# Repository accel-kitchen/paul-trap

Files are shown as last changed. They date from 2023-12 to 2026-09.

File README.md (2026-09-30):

# Printable Paul Trap

This repository contains the 3D-printable parts and assembly documentation for a compact Paul trap designed for physics education. The system consists of a high-voltage power-supply module, a protective enclosure, and a choice of two electrode modules:

- a **ring-electrode module** with integrated illumination and a camera mount; or
- a **linear-electrode module** for quantitative observation and charge-to-mass-ratio measurements.

The repository is intended primarily as a build resource. For the complete photo-based instructions, see the [assembly manual](manual/manual.pdf). Videos of trapped particles are available in the [demonstration playlist](https://www.youtube.com/playlist?list=PLJxrDB4DxPX1ZcciUAjnfQ3G_OaAEvvxG).

> [!CAUTION]
> This apparatus uses **high voltage (up to several kilovolts)**. It is not a toy and must not be assembled or operated without appropriate laboratory supervision. High-voltage and mains-voltage wiring must be performed and inspected by a qualified person. Disconnect the power source, verify that the circuit is de-energized, and discharge the system before touching electrodes, terminals, wiring, or internal components. Follow all applicable electrical-safety rules at your institution.

## Contents

- [Before you start](#before-you-start)
- [Choose a trap configuration](#choose-a-trap-configuration)
- [Recommended build order](#recommended-build-order)
- [3D printing notes](#3d-printing-notes)
- [Parts and materials](#parts-and-materials)
- [Assembly overview](#assembly-overview)
- [Final inspection and commissioning](#final-inspection-and-commissioning)
- [Repository layout](#repository-layout)
- [Publication](#publication)
- [License](#license)

## Before you start

1. Read this README and the complete [assembly manual](manual/manual.pdf).
2. Choose either the ring-electrode or linear-electrode configuration.
3. Print all required STL files before purchasing or modifying hardware.
4. Dry-fit the printed parts and check all screw holes, slots, camera mounts, and cable routes.
5. Assemble and test the mechanical and low-voltage sections first.
6. Do not connect the high-voltage source until the entire assembly has been inspected.

The STL files are provided as finished meshes. Source CAD files and printer-specific slicing profiles are not included, so print tolerances may need to be adjusted for your printer.

## Choose a trap configuration

| Configuration | Main features | Important notes |
| --- | --- | --- |
| **Ring electrode** | Ring electrode with two endcaps, integrated LED illumination, internal camera mount, compact enclosure | The more integrated of the two designs. The documented electrode spacing was designed for operation up to 6 kV. |
| **Linear electrode** | Four-rod quadrupole, optional ruler for image calibration, separate bottom plate | This design is an experimental prototype and is less integrated. The documented setup used an external camera, an acrylic enclosure, and a laser pointer. The applied voltage was limited to approximately 2.1 kV. |

The quoted voltages describe the documented apparatus; they are **not** general operating recommendations. Safe limits depend on construction quality, insulation, electrode spacing, environment, and institutional procedures.

## Recommended build order

Build the modules in the following order:

1. **Shielding box** — protects trapped particles from air currents and reduces stray light.
2. **Power-supply enclosure** — houses the high-voltage transformer and switch.
3. **Electrode module** — assemble either the ring-electrode or linear-electrode version.
4. **Illumination and imaging** — install the LED or external light source and align the camera.
5. **Mechanical inspection** — check fasteners, clearances, cable strain relief, and exposed conductors.
6. **Electrical inspection and commissioning** — to be performed under qualified supervision.

## 3D printing notes

- Print the STL files at their original scale unless you intentionally redesign the mating parts.
- Use an opaque black material for `shielding_box.stl`, or paint the inside black, to reduce stray light.
- The M3 holes in the shielding box are modeled at approximately 3 mm and are not pre-tapped.
- Several press-fit parts are intentionally tight. Remove supports and clean edges before applying force.
- Check that conductive parts, screws, and wires cannot cut into insulation or contact the enclosure unexpectedly.
- Inspect printed parts for cracks, delamination, heat damage, and sharp edges before use.

## Parts and materials

The following lists summarize the hardware used in the documented build. Equivalent components may be used only after checking their electrical, mechanical, and safety ratings.

### Shielding box

Printed parts:

- [`shielding_box.stl`](stl_file/shielding_box/shielding_box.stl)
- [`window.stl`](stl_file/shielding_box/window.stl)

Additional hardware:

- M3 screws

### Power-supply module

Printed parts:

- [`power_supply_module_box.stl`](stl_file/power_supply_module/power_supply_module_box.stl)
- [`power_supply_module_box_lid.stl`](stl_file/power_supply_module/power_supply_module_box_lid.stl)

Components used in the documented build:

- toggle switch: S-21A, NKK Switches
- high-voltage transformer: UFO-6K-001-P100, Union Electric
- appropriately rated power cable
- two banana plugs
- suitable screws and nuts for securing the transformer

The documented transformer accepts 50/60 Hz AC at 0–100 V and has a nominal voltage ratio of 60. Treat both the input wiring and output wiring as hazardous.

### Ring-electrode module

Printed electrode parts:

- [`ring_electrode.stl`](stl_file/ring_type/ring_electrode.stl)
- [`endcap.stl`](stl_file/ring_type/endcap.stl)
- [`electrode_holder.stl`](stl_file/ring_type/electrode_holder.stl)

Printed enclosure and accessory parts:

- [`ring_trap_box.stl`](stl_file/ring_type/ring_trap_box.stl)
- [`ring_trap_box_lid.stl`](stl_file/ring_type/ring_trap_box_lid.stl)
- [`LED_holder.stl`](stl_file/ring_type/LED_holder.stl)
- [`camera_jig.stl`](stl_file/ring_type/camera_jig.stl)

Electrode hardware:

- conductive paint (SKU-0216, Bare Conductive, in the documented build)
- M3 low-profile screws, 4 mm
- jumper wires and crimp terminals
- M4 screws, 10 mm; hex-socket screws are recommended

Illumination and imaging:

- bright LED, preferably blue-toned
- breadboard, jumper wires, resistor, and 9 V battery
- toggle switch: RS PRO 448-0753
- battery strap: RS PRO 489-021
- USB camera: USB130W01MT-MF40-J in the documented build
- 1/4-inch camera screw

Main-body hardware:

- two banana sockets: Stäubli 23.3020-21
- two 10 MΩ resistors: TE Connectivity HB110MFZRE
- crimp terminals and insulated wiring

### Linear-electrode module

Printed parts:

- [`electrode_jig1.stl`](stl_file/linear_type/electrode_jig1.stl)
- [`electrode_jig2.stl`](stl_file/linear_type/electrode_jig2.stl)
- two copies of [`electrode_jig_stopper.stl`](stl_file/linear_type/electrode_jig_stopper.stl)
- [`linear_trap_box.stl`](stl_file/linear_type/linear_trap_box.stl)
- [`linear_trap_box_lid.stl`](stl_file/linear_type/linear_trap_box_lid.stl)
- [`ruler_jig.stl`](stl_file/linear_type/ruler_jig.stl)

Additional hardware:

- four metal rods, approximately 3 mm in diameter and 75 mm long
- insulated wire and crimp terminals
- conductive metal plate, approximately 55 × 55 × 3 mm
- three banana sockets: Stäubli 23.3020-21
- two 10 MΩ resistors: TE Connectivity HB110MFZRE
- ruler for image calibration, if required
- external camera and enclosure; the documented setup used a Logicool C920n camera and an acrylic box

## Assembly overview

This section provides the build sequence. Refer to the [assembly manual](manual/manual.pdf) and the photographs under [`img/`](img/) for detailed views.

### 1. Shielding box

1. Print the box and window.
2. Clean the mating surfaces and verify that the window opens and closes freely.
3. Attach the window using M3 hardware.
4. If the enclosure is not opaque, paint the inside black before installing the trap.

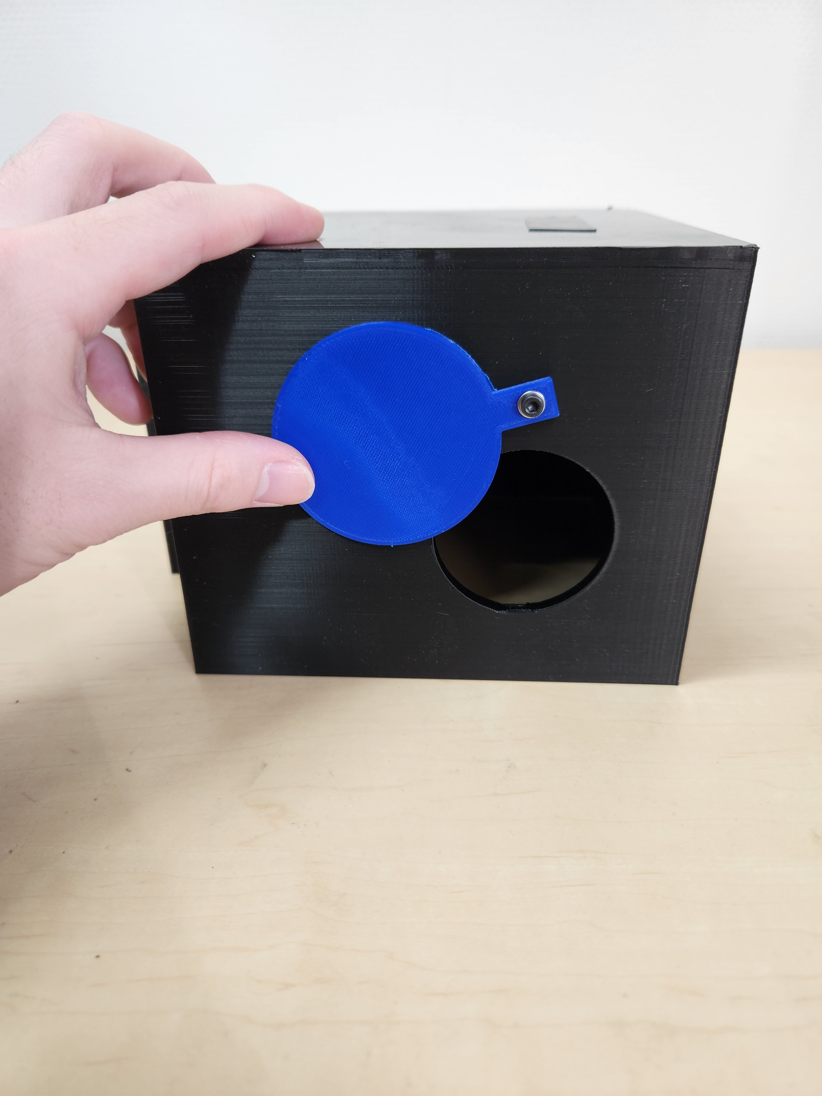
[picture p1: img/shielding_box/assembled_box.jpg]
Assembled shielding box


### 2. Power-supply enclosure

> [!WARNING]
> Do not perform mains-voltage or high-voltage wiring unless you are qualified to do so. The enclosure does not make an incorrectly wired circuit safe.

1. Print the enclosure and lid, then dry-fit the transformer, switch, cables, and banana connectors.
2. Have a qualified person complete and inspect the electrical wiring shown in the manual.
3. Secure the transformer so that it cannot move or strain the wiring.
4. Add strain relief and insulation appropriate for the cable and voltage ratings.
5. Close the enclosure before any energized test.

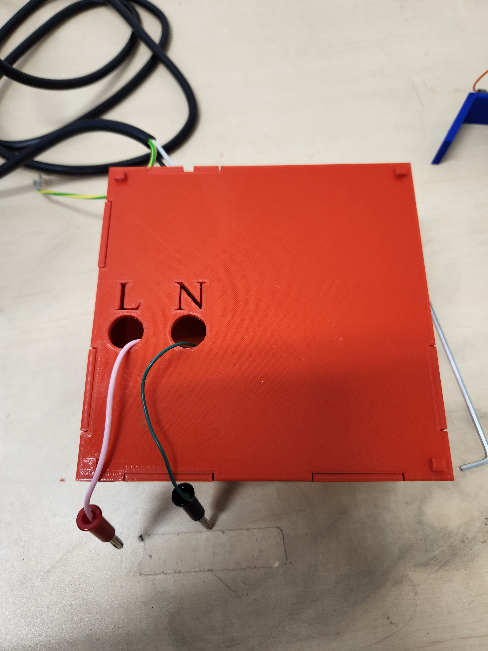
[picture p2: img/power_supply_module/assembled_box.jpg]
Assembled power-supply enclosure


### 3A. Ring-electrode module

1. Apply conductive paint to the ring electrode and both endcaps. Allow it to dry completely; apply additional coats if coverage is poor.
2. Prepare wires with crimp terminals and attach them to the electrodes using the low-profile screws.
3. Mount the electrodes in `electrode_holder.stl`, keeping the orientation shown in the manual.
4. Assemble and test the LED circuit separately at low voltage.
5. Install the two banana sockets in the main enclosure.
6. Install one 10 MΩ series resistor between each high-voltage input and its electrode connection, following the documented wiring and institutional safety requirements.
7. Place the LED circuit inside the enclosure and route the LED and electrode leads through the lid.
8. Install the camera jig and camera.
9. Insert the electrode holder and LED holder into the lid, then connect the electrode leads to the resistor terminals.
10. Confirm that the ring and endcaps are aligned and that no exposed conductor can contact the enclosure or camera hardware.

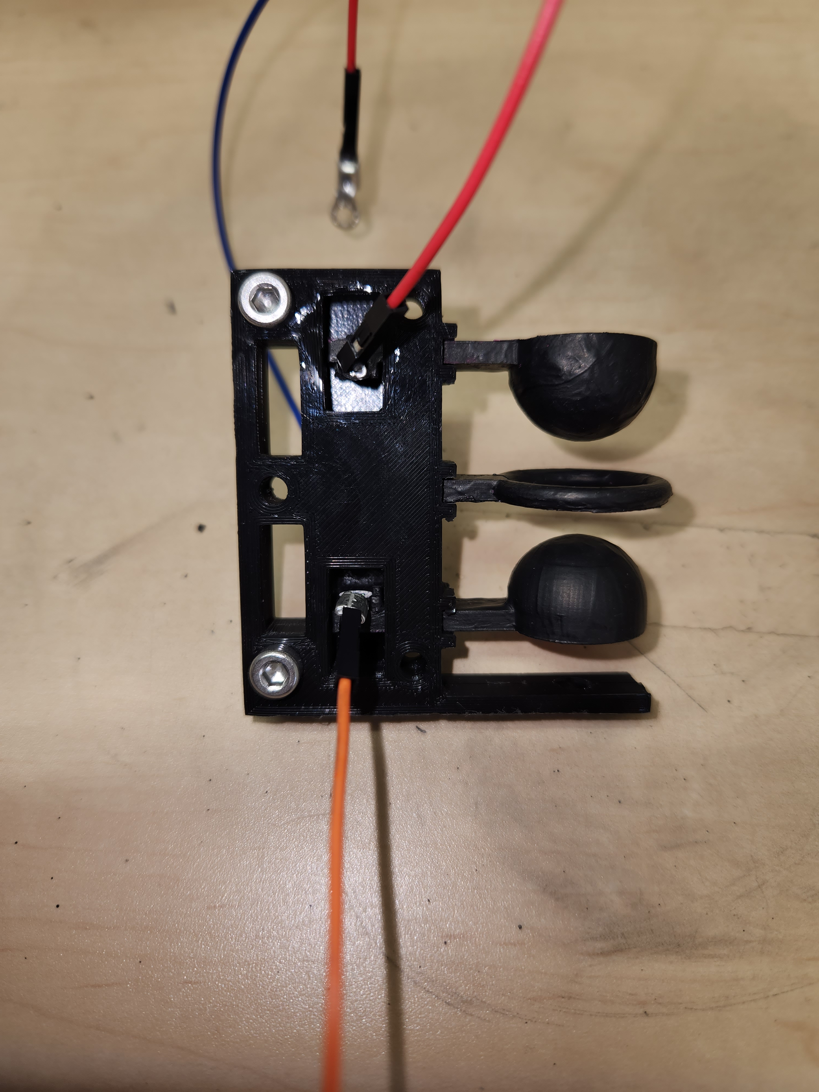
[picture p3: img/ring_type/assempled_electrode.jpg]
Ring-electrode assembly


### 3B. Linear-electrode module

1. Insert the four metal rods into `electrode_jig1.stl`.
2. Fit `electrode_jig2.stl` over the rods and secure the assembly.
3. Wire diagonally opposite rods together to form the two electrode pairs of the quadrupole.
4. Route the wires away from adjacent conductors and add insulation where discharge could occur.
5. Lock the electrode assembly into the enclosure using the two printed stoppers.
6. Prepare the bottom plate and provide a secure electrical connection to it.
7. Install the three banana sockets: two for the quadrupole supply and one for the bottom plate.
8. Install the two 10 MΩ series resistors on the high-voltage inputs.
9. Place the bottom plate in the lid, connect it, close the enclosure, and install the electrode assembly.
10. If required, install the ruler and ruler jig for image calibration.
11. Place the complete trap inside a suitable protective enclosure and align the external camera and light source.

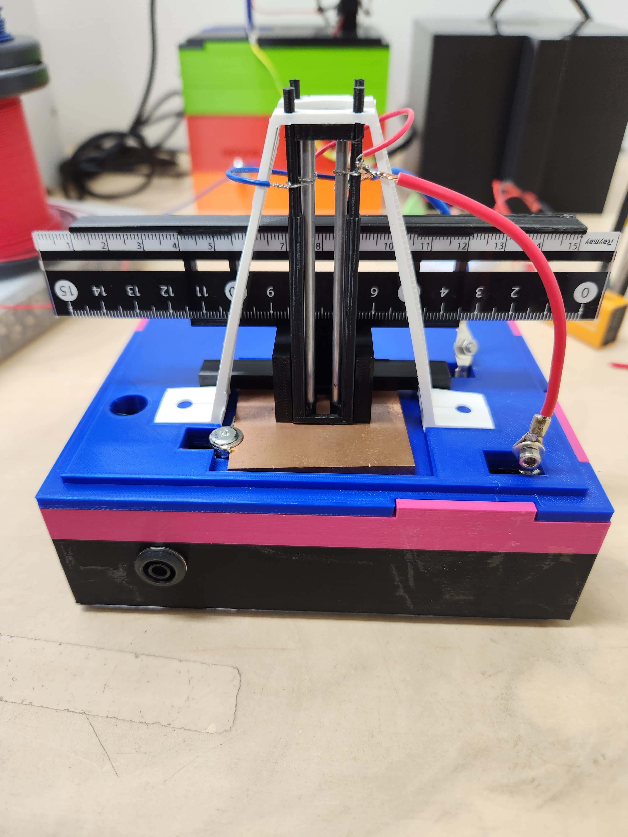
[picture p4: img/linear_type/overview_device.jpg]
Linear-electrode module


## Final inspection and commissioning

Before applying power, verify all of the following:

- all printed parts are intact and securely fastened;
- the electrode geometry matches the manual;
- high-voltage conductors are insulated, mechanically secured, and separated appropriately;
- the 10 MΩ series resistors are installed correctly;
- no bare terminal is accessible during operation;
- cables have strain relief and cannot be pulled into the electrodes;
- the power-supply enclosure is closed;
- the camera and illumination system work before high voltage is enabled;
- a qualified person has inspected the complete electrical assembly;
- an emergency shutdown procedure is understood by everyone present.

Begin commissioning at the lowest practical input and increase it only under controlled laboratory procedures. Never adjust, reconnect, or reposition the apparatus while energized.

## Repository layout

```text
.
├── img/                  # Assembly and reference photographs
├── manual/
│   └── manual.pdf        # Complete photo-based assembly manual
├── stl_file/
│   ├── shielding_box/    # Protective enclosure
│   ├── power_supply_module/
│   ├── ring_type/        # Ring-electrode trap
│   └── linear_type/      # Linear-electrode trap
├── LICENSE
└── README.md
```

## Publication

The design and its use in charge-to-mass-ratio measurements are described in:

R. J. Saito, T. A. Tanaka, Y. Sakemi, M. Yagyu, and K. S. Tanaka, “Measurement of the charge-to-mass ratio of particles trapped by the Paul trap for education,” *Physics Education* **59** (2024) 025028. [https://doi.org/10.1088/1361-6552/ad27a8](https://doi.org/10.1088/1361-6552/ad27a8)

```bibtex
@article{Saito2024PaulTrap,
  author  = {Saito, R. J. and Tanaka, T. A. and Sakemi, Y. and Yagyu, M. and Tanaka, K. S.},
  title   = {Measurement of the charge-to-mass ratio of particles trapped by the Paul trap for education},
  journal = {Physics Education},
  volume  = {59},
  number  = {2},
  pages   = {025028},
  year    = {2024},
  doi     = {10.1088/1361-6552/ad27a8}
}
```

## License

This repository is distributed under the [MIT License](LICENSE).

The license covers the files in this repository. Commercial components, photographs, third-party product names, and referenced publications may be subject to their own terms.

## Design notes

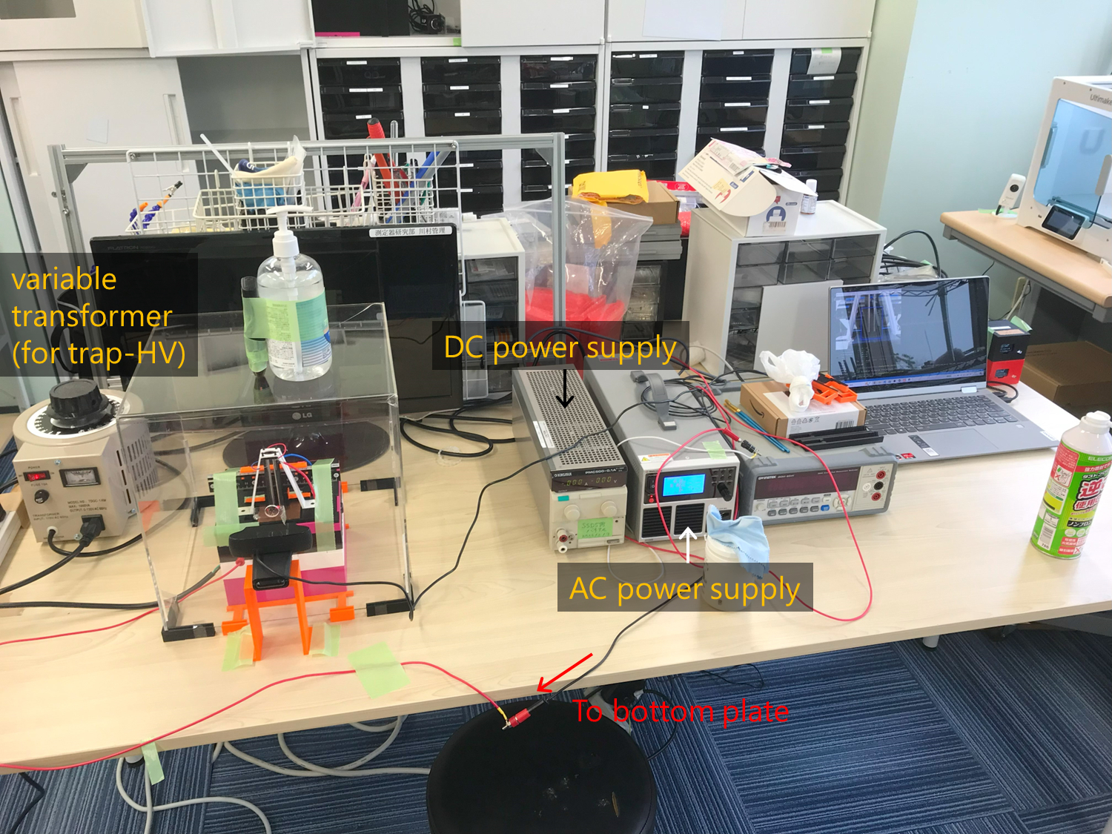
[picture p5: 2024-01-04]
img/linear_type/overview2.jpg

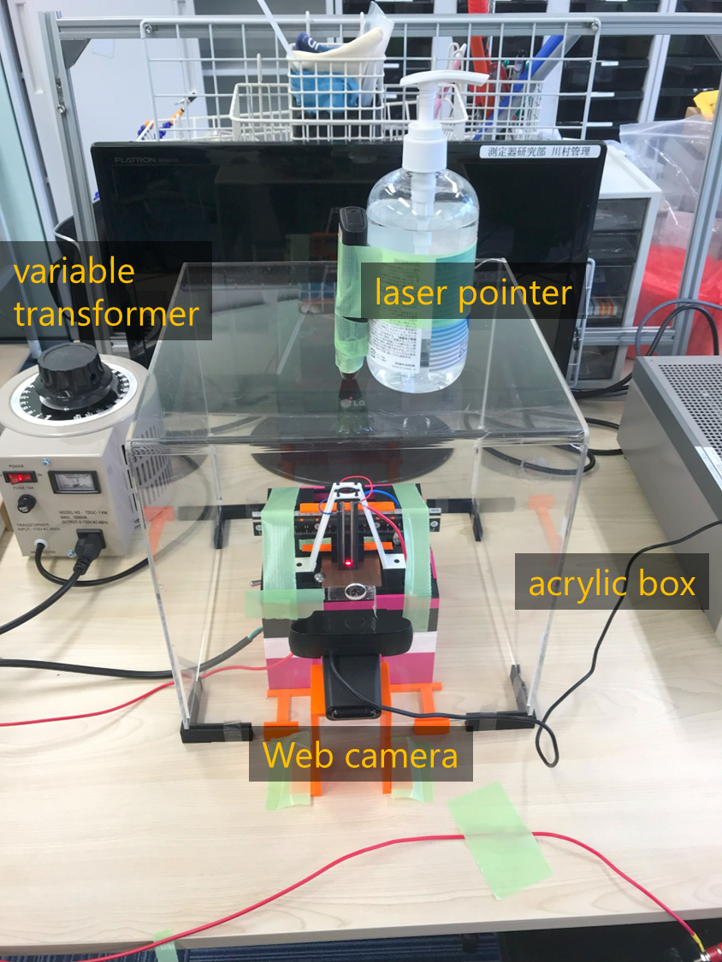
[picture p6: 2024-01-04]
img/linear_type/overview1.jpg

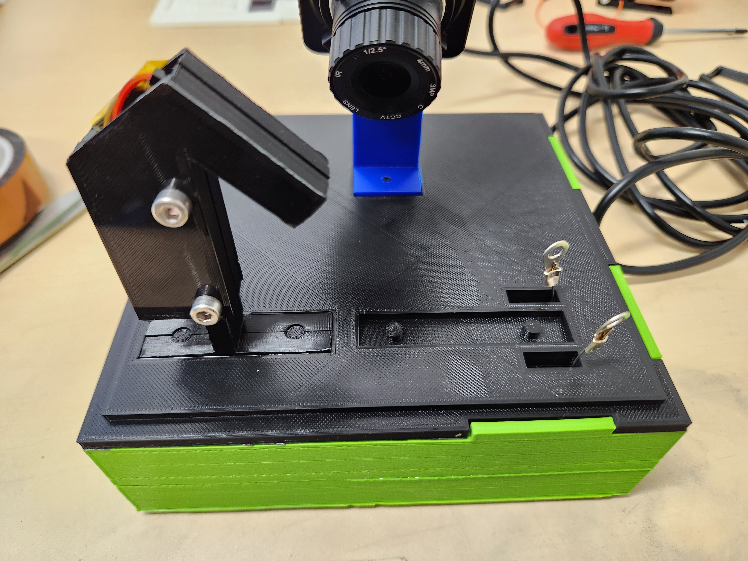
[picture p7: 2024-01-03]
img/ring_type/LED_holder_and_lid.jpg

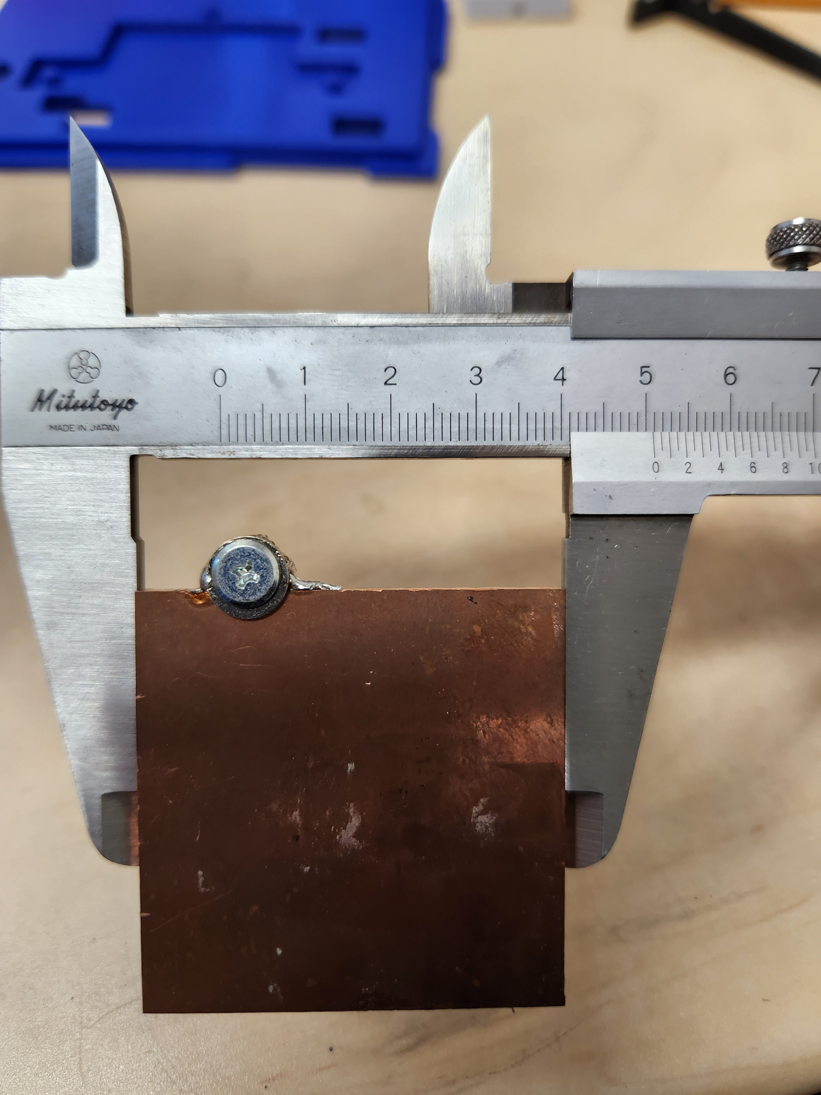
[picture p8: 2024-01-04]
img/linear_type/size_plate.jpg

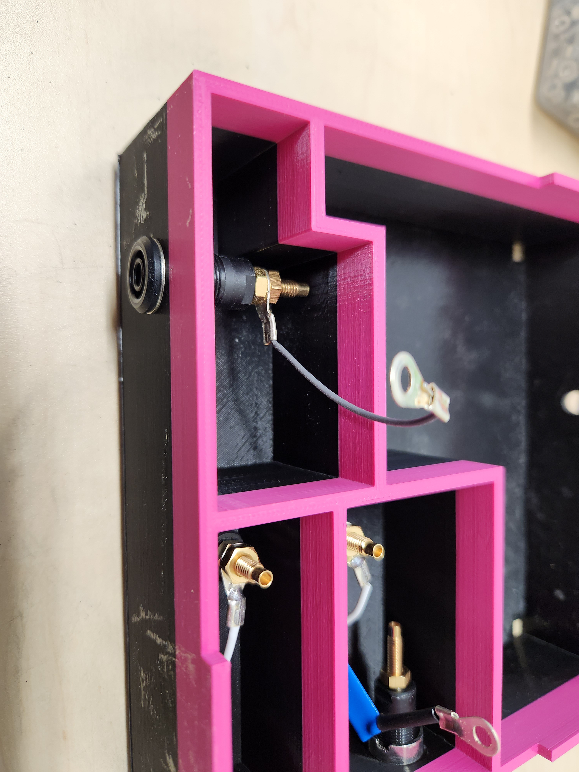
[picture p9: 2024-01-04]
img/linear_type/plate_side.jpg

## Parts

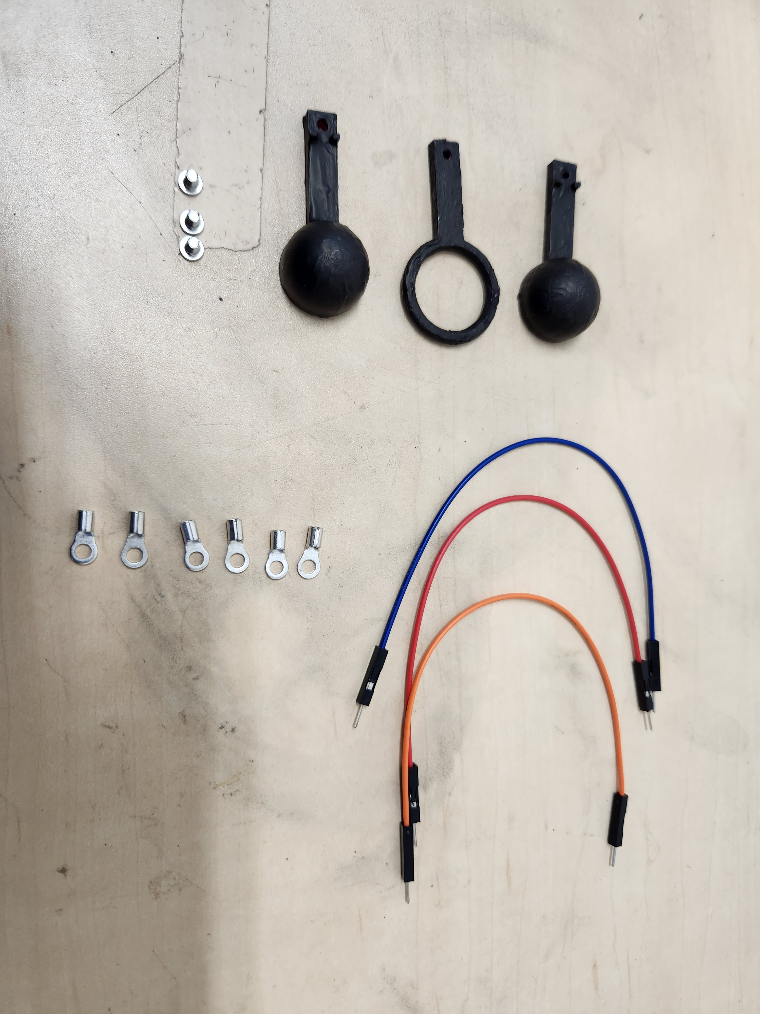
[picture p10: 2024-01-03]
img/ring_type/electrode_parts.jpg

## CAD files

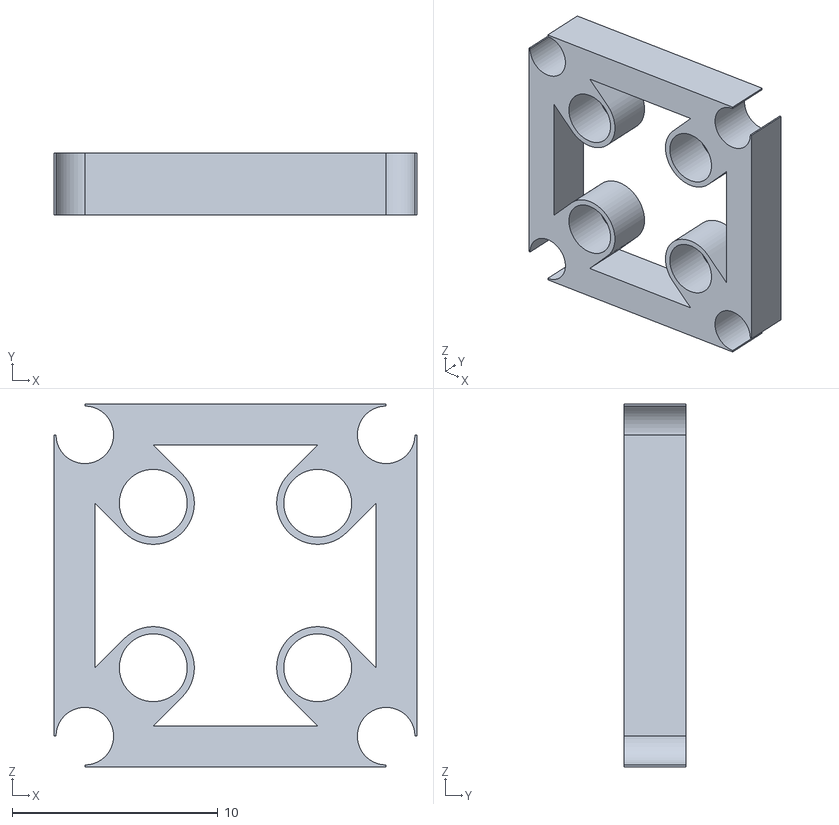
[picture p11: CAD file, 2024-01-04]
stl_file/linear_type/electrode_jig2.stl
17.7 x 3.00 x 17.7

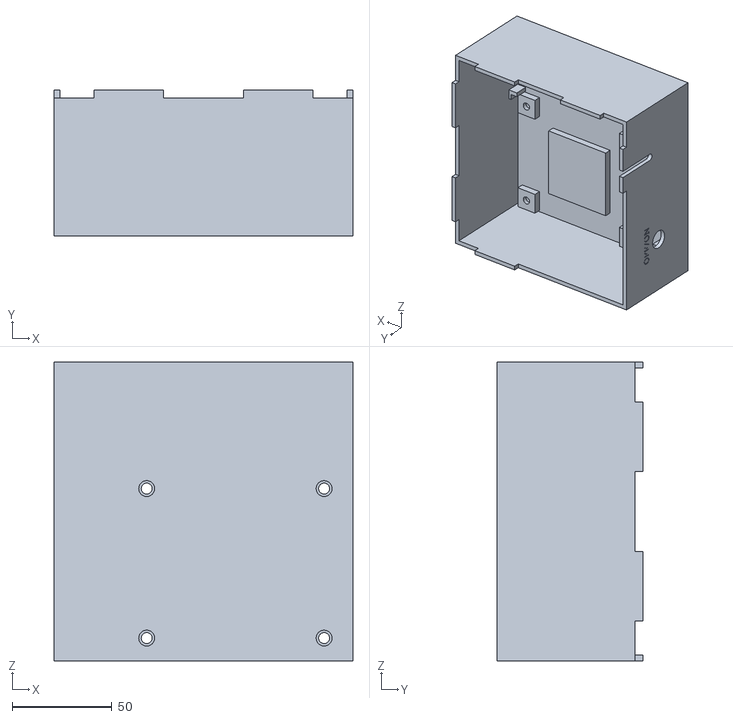
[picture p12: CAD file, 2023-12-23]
stl_file/power_supply_module/power_supply_module_box.stl
150.0 x 73.0 x 150.0

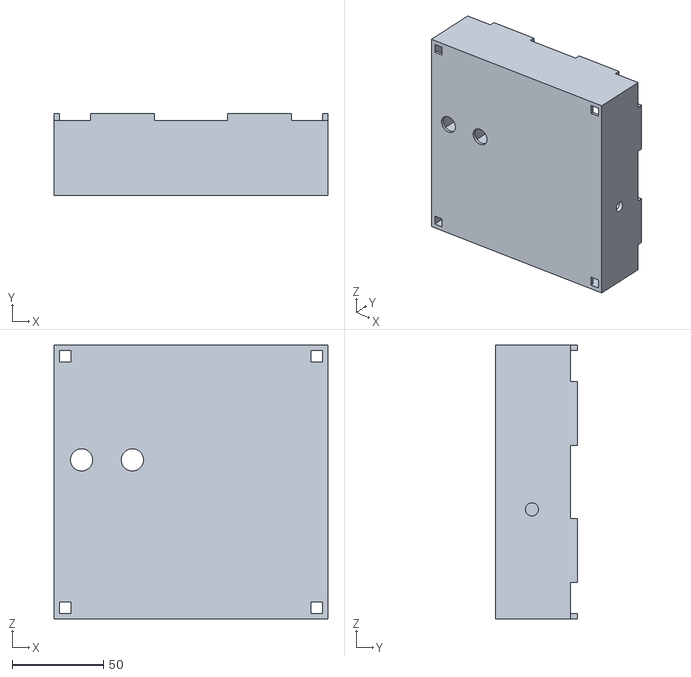
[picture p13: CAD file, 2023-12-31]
stl_file/ring_type/ring_trap_box.stl
150.0 x 45.0 x 150.0

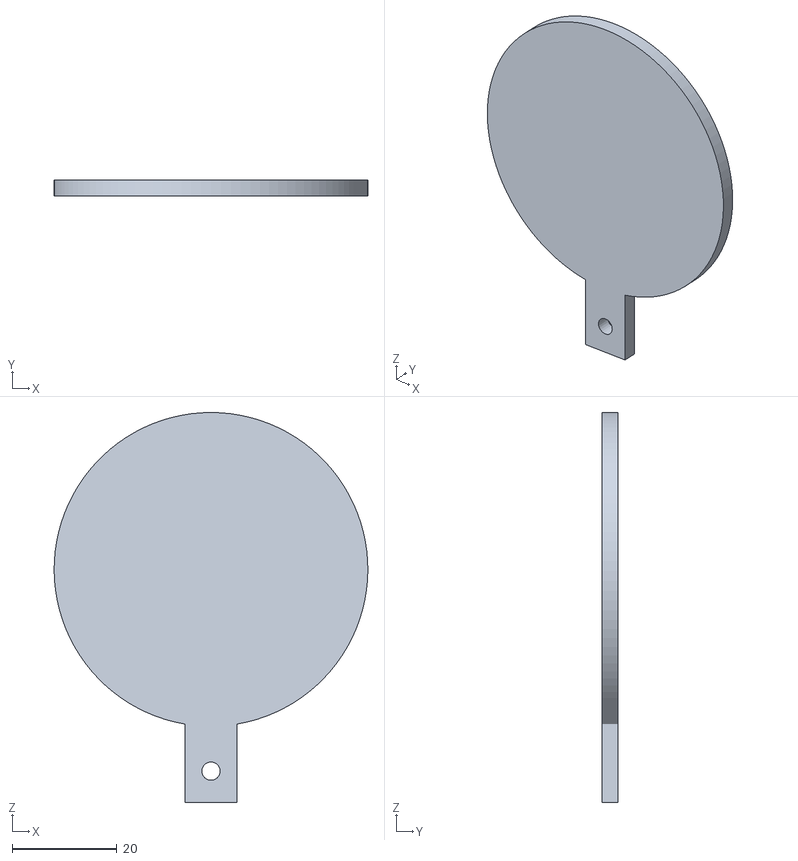
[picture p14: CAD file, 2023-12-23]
stl_file/shielding_box/window.stl
60.0 x 3.00 x 74.6

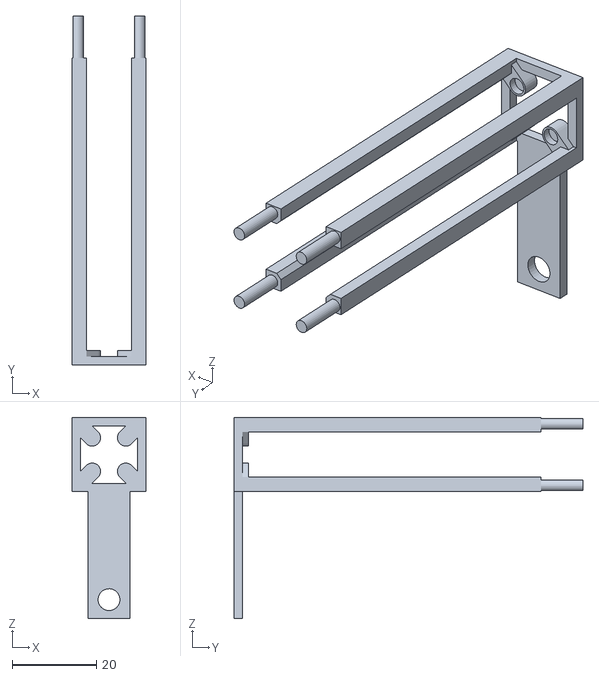
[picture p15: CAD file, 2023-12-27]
stl_file/linear_type/electrode_jig1.stl
17.7 x 83.0 x 47.8

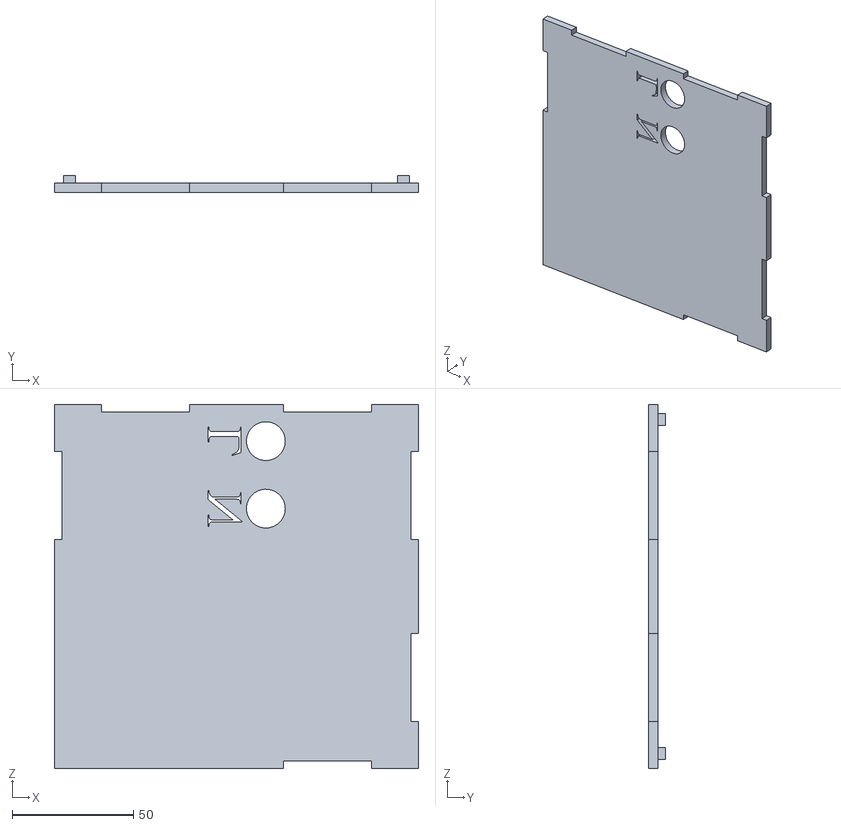
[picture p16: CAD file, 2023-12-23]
stl_file/power_supply_module/power_supply_module_box_lid.stl
150.0 x 7.00 x 150.0

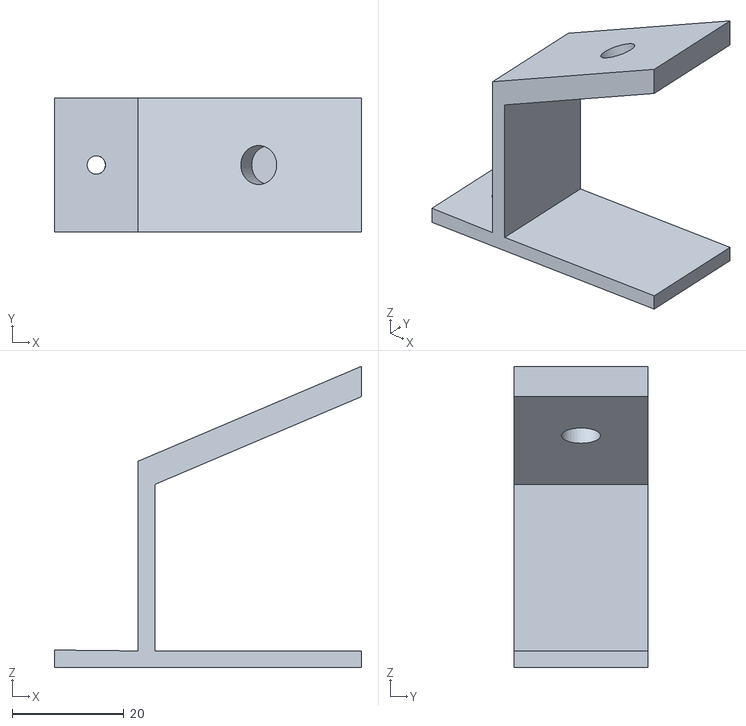
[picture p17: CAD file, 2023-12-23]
stl_file/ring_type/camera_jig.stl
55.0 x 24.0 x 54.0

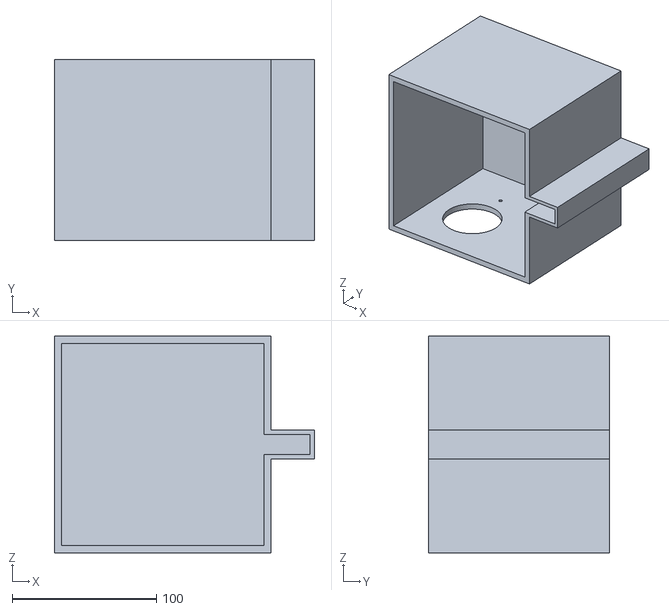
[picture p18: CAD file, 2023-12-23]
stl_file/shielding_box/shielding_box.stl
180.0 x 125.0 x 150.0

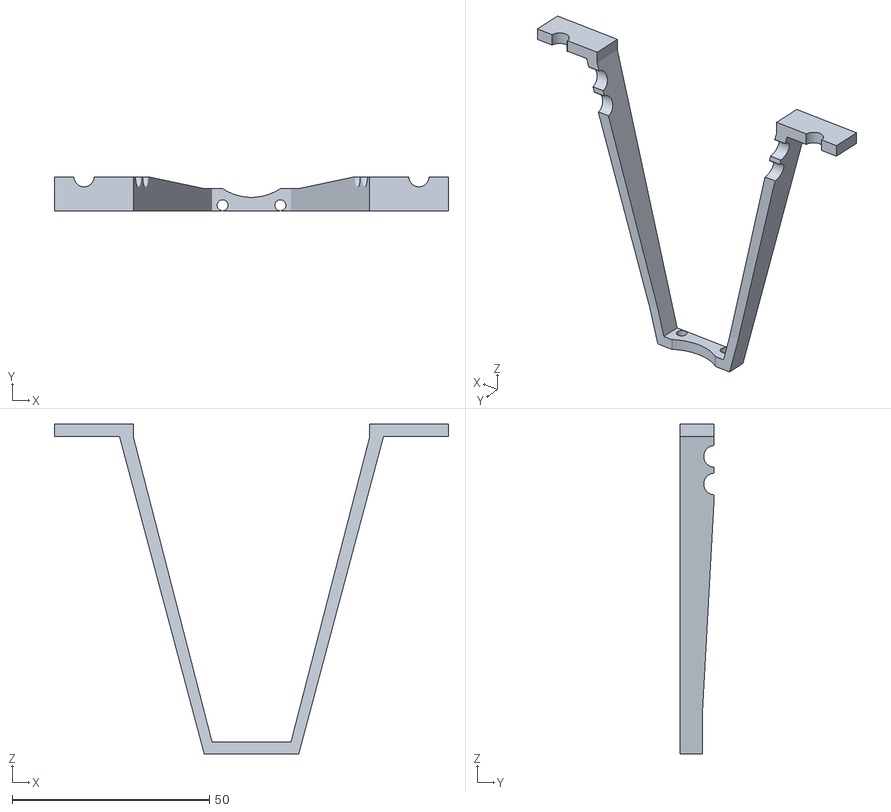
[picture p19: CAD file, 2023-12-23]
stl_file/linear_type/electrode_jig_stopper.stl
100.0 x 8.73 x 83.7

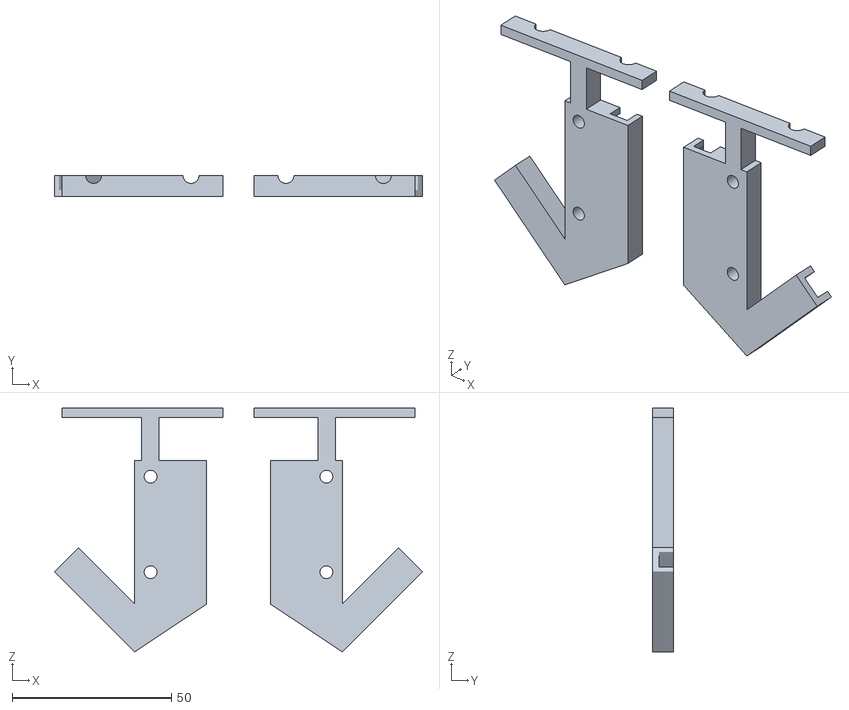
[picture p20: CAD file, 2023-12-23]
stl_file/ring_type/LED_holder.stl
115.6 x 6.60 x 76.5

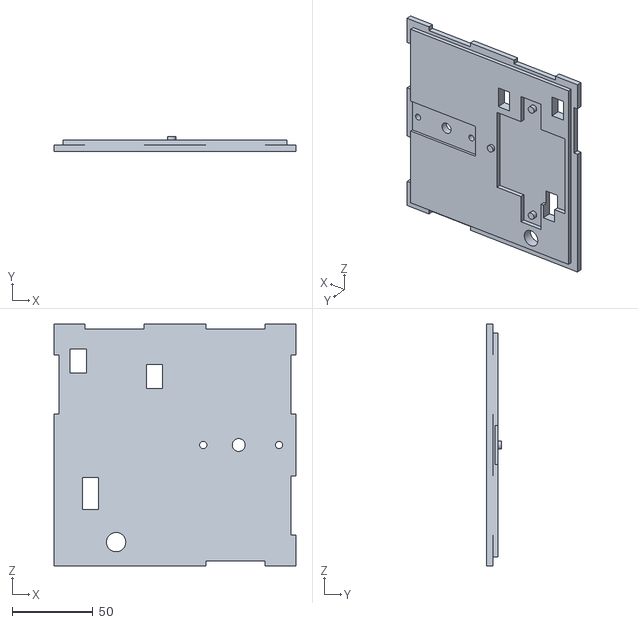
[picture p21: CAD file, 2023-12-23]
stl_file/linear_type/linear_trap_box_lid.stl
150.0 x 9.00 x 150.0

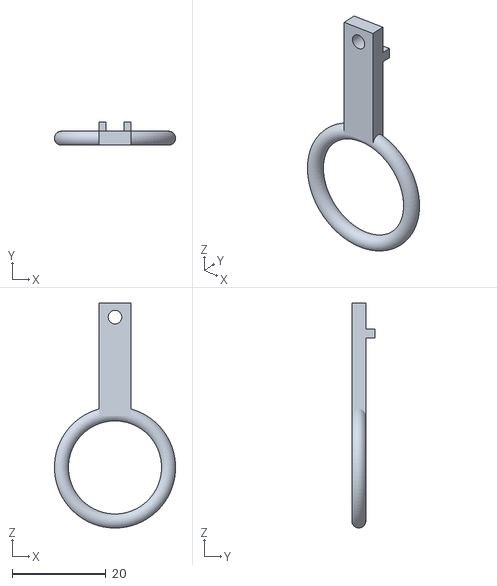
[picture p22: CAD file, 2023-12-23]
stl_file/ring_type/ring_electrode.stl
25.8 x 5.00 x 47.9

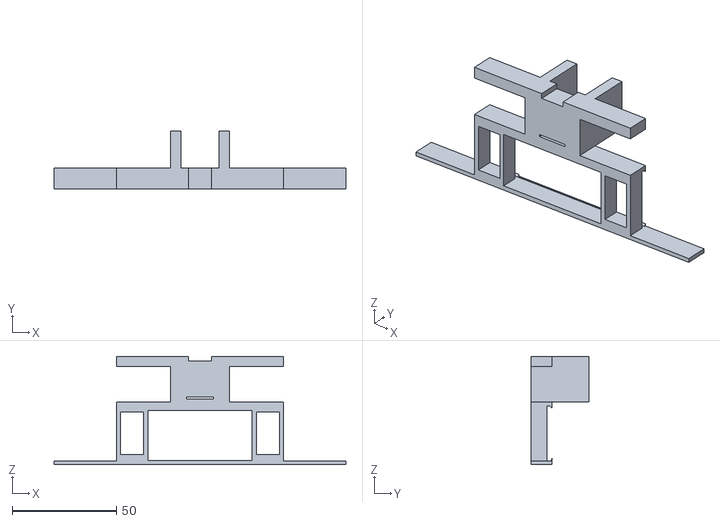
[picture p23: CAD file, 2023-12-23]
stl_file/linear_type/ruler_jig.stl
140.0 x 27.7 x 52.0

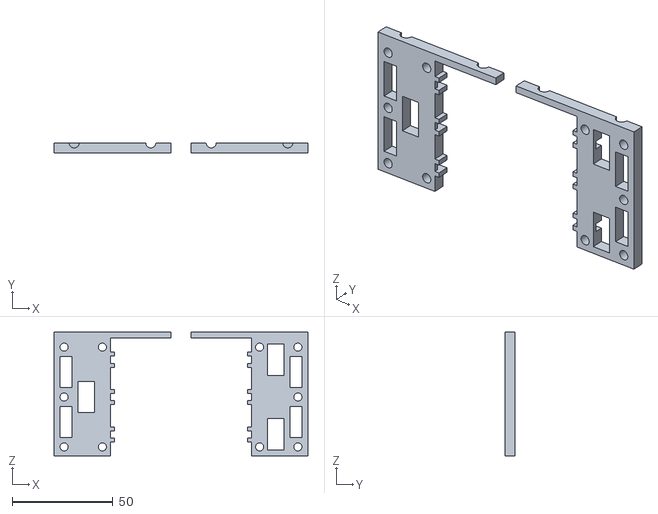
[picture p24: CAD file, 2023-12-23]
stl_file/ring_type/electrode_holder.stl
126.0 x 5.10 x 61.5

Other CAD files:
stl_file/linear_type/linear_trap_box.stl
stl_file/ring_type/ring_trap_box_lid.stl
stl_file/ring_type/endcap.stl

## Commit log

2023-12-23 add 3d model
    [LED_holder.stl, camera_jig.stl, cover_box.stl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]
2023-12-27 modify stl file
    [electrode_jig1.stl]
2023-12-28 change file name
    [shielding_box.stl, window.stl]
2023-12-31 update ring trap box
    [ring_trap_box.stl]
2024-01-03 create manual and add photograph
    [electrode_holder.stl]
2024-01-04 add linear-type
    [electrode_jig2.stl, electrode_jig_stoper.stl, electrode_jig_stopper.stl]
2026-09-30 Rewrite assembly documentation
